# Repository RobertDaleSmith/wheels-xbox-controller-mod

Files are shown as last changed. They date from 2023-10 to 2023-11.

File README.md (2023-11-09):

# Xbox Controller Accessibility Mod for Dayton (Wheels)

This project is dedicated to enhancing the gaming experience for Dayton, known in the gaming community as [Wheels](https://twitter.com/WheelsFGC). It involves modifying an Xbox controller to interface with a QT Py RP2040 microcontroller. The modification reads inputs from the controller's analog sticks and manages digital outputs to trigger buttons, making the controller more accessible and comfortable for Wheels to use.

## Features

- Custom interaction with the Xbox controller's right analog stick to intuitively use the Left Bumper (L1) and Left Trigger (L2) buttons.
- A transistor-based circuit to enable the QT Py RP2040 to sink current, necessary for activating the Left Bumper button.

## Components

- Adafruit QT Py RP2040 Microcontroller
- Xbox controller
- Connection wires
- 2N5551 NPN Transistor
- 10k Ohm resistor

## Circuit Diagram/Connections

Below is the schematic represented through ASCII art showing the basic setup:

```
   [Xbox Controller]               [QT Py RP2040]             [2N5551 Transistor]

           3.3V Power (TP9) ----------- VCC
            Right Stick GND ----------- GND -------------------- Emitter
Right Stick Potentiometer X ----------- GPIO A0
Right Stick Potentiometer Y ----------- GPIO A1
 Left Trigger Sensor (TP68) ----------- GPIO A2
                                        GPIO A3 ---- [10kΩ] ---- Base
Left Bumper (Button Signal) ------------------------------------ Collector
```

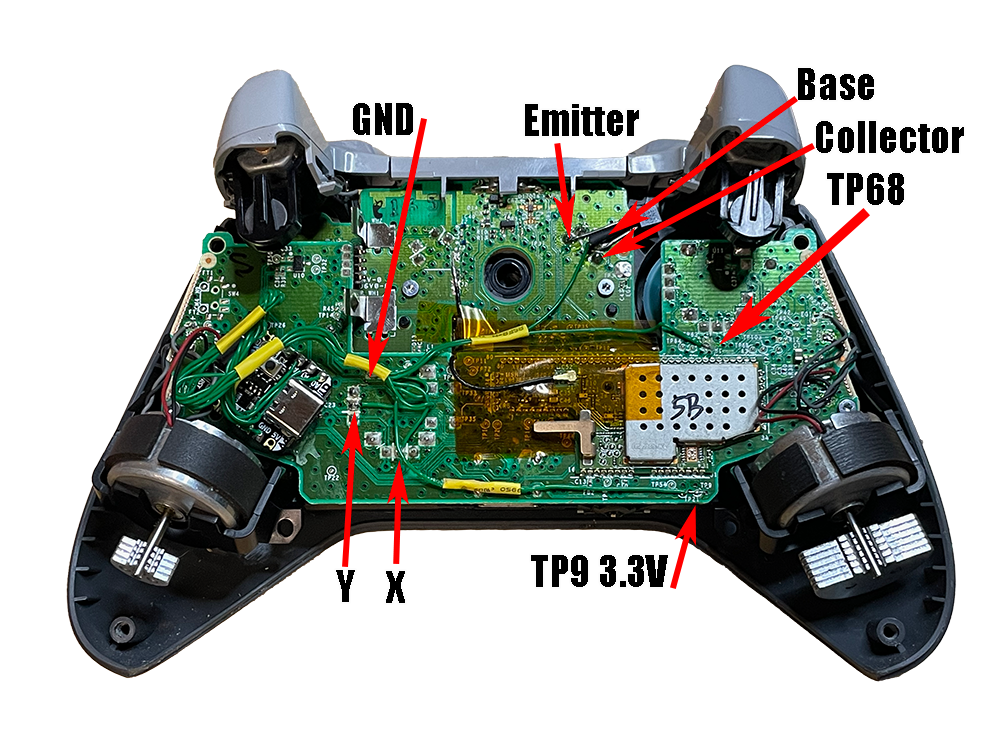
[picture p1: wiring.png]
wiring-diagram


- The 3.3V power supply (VCC) is taken from TP9 on the controller's PCB.
- The ground connection is established with the ground pin of the right analog stick.
- The X and Y center pins of the right analog stick's potentiometers are connected to the QT Py's GPIO A0 and A1, respectively.
- GPIO A2 is connected to TP68 on the Xbox controller's PCB, used for triggering the Left Trigger (L2).
- For the Left Bumper (L1), GPIO A3 is connected through a 10k ohm resistor to the base of a 2N5551 NPN transistor. The emitter of the transistor is connected to the ground, and the collector is tied to the Left Bumper button's signal line.

## Code Overview

The firmware simply loops over and over checking the Right Ananlog stick's Y-axis position. If pressed up, then it activates Left Trigger at 100% pressed. If pressed, down, then it activates the Left Bumper button.

- The code initializes input and output pins and begins serial communication for debugging purposes.
- In the loop, it reads values from the analog stick, maps these values to a range suitable for game interaction, and prints them to the serial monitor for debugging.
- It checks the Y-position of the stick to decide whether to activate L1 or L2 by manipulating GPIO A2 and A3.

## Building the Project

1. **Controller Preparation:** This involves safely opening the controller, locating points of interest on the PCB, and planning the modification without hindering the controller's original functionality.
2. **Making Connections:** This step requires careful soldering to establish reliable connections between the controller and the QT Py RP2040.
3. **Environment Setup:** Set up the development environment for the QT Py RP2040 with Arduino IDE.
4. **Configuration and Calibration:** Detail any necessary steps for calibrating the analog sticks' inputs, considering their range and sensitivity.

## Challenges and Solutions

One significant challenge was managing the Left Bumper button signal. Initially, the microcontroller couldn't sink the current from the button's signal line. The successful solution was implementing an external pull-down setup using a 2N5551 NPN transistor.

## USB Wire Locking Mechanism

The ability to lock the USB cable into place and prevent accidental removals was also requested for this project. So the Wire Lock Block was created:

[printables.com/model/641099-controller-wire-lock-block-xbox-one-s](https://www.printables.com/model/641099-controller-wire-lock-block-xbox-one-s)

Custom Wheels back plate model for this is included here as well.

## Future Improvements

This example code can be expanded to trigger on the X-axis or even at diagonal directions. In the future both ananlog sticks could be sniffed and trigger multiple buttons depending on your specific needs.

## Acknowledgments

This project was inspired by and designed for [Dayton "Wheels"](https://twitter.com/WheelsFGC), a prominent figure in the FGC (Fighting Game Community) known for his perseverance and skill, competing at the highest levels despite his physical challenges. This mod aims to make gaming more accessible and enjoyable for him and hopefully others in need of similar solutions.

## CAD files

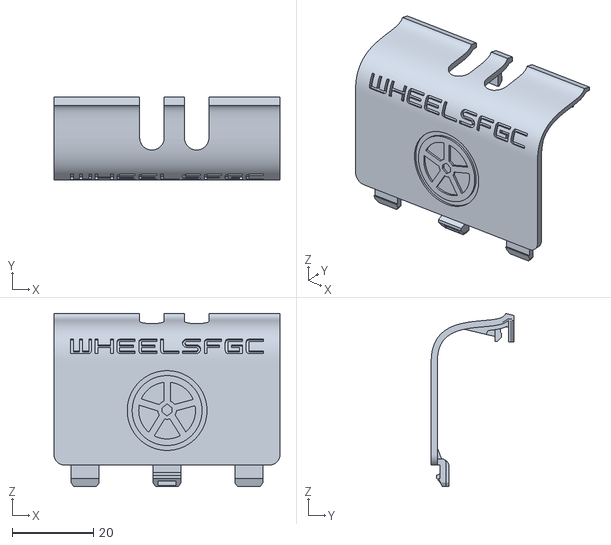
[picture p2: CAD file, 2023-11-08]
XBOX_WHEELS_BATTERY_COVER.stl
55.6 x 20.3 x 42.6

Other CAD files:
XBOX_WHEELS_BATTERY_COVER.f3d

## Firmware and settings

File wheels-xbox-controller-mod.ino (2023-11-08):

// define the pins used in the program
const int analogInputPins[] = {A0, A1, A2, A3}; // Analog input pins
const int floatingOutputPins[] = {A2, A3}; // Analog pins used as floating digital outputs

void setup() {
  Serial.begin(115200); // Start serial communication at a baud rate of 9600
  
  // configure the input pins
  for (int i = 0; i < 2; i++) {
    pinMode(analogInputPins[i], INPUT);
  }

  // configure the output pins
  for (int i = 0; i < 2; i++) {
    pinMode(floatingOutputPins[i], OUTPUT);
    // Instead of driving the pin HIGH or LOW, we're setting it to a high-impedance state, effectively making it floating.
    digitalWrite(floatingOutputPins[i], LOW); // This is necessary to ensure the pins are in a known state, but they will remain effectively floating since we're not setting them HIGH.
  }

}

void loop() {
  // read the input on analog pins and print them to the serial monitor
  // Read the analog input values from the joystick
  int rawValueX = analogRead(analogInputPins[0]);
  int rawValueY = analogRead(analogInputPins[1]);

  // Map these values to the range 0-255
  int mappedValueX = map(rawValueX, 0, 1023, 0, 255);
  int mappedValueY = map(rawValueY, 0, 1023, 0, 255);

  // Output the mapped values - this is just for debugging and can be removed later
  Serial.print("X: ");
  Serial.print(mappedValueX);
  Serial.print("\tY: ");
  Serial.println(mappedValueY);

  // Right Stick Up == L2
  if (mappedValueY < 50) {
    pinMode(A2, OUTPUT);
    digitalWrite(A2, LOW);
  } else {
    pinMode(A2, INPUT);
  }

  // Right Stick Down == L1
  if (mappedValueY > 90) {
    pinMode(A3, OUTPUT);
    digitalWrite(A3, HIGH);
  } else {
    pinMode(A3, INPUT);
  }
}
